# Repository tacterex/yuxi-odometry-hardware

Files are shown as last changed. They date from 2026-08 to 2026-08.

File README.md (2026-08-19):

# YUXI ODOMETRY HARDWARE DOCUMENTATION

## External References

* For **software documentation**, see the [YUXI Odometry Software repository](https://github.com/tacterex/yuxi-odometry-software-c).
* For the **FTC SDK library**, see: **TBA**

## Short description

This documentation provides instructions for assembling and using the YUXI ODOMETRY SET.

This document does not cover the electronic assembly of the odometry set. For mechanical assembly instructions, refer to the hardware documentation linked above. Instead, this document focuses on the electronic schematics, firmware, and software capabilities of the system.

Keep in mind that the electronics assembly affects some aspects of the mechanical assembly. Therefore, make sure to read both the hardware and software documentation carefully before starting the assembly.

## Recommended 3D Printer Settings

The 3D-printed parts were designed and tested using the following printer settings:

| Setting | Recommended value |
| --- | --- |
| Printer | Prusa i3 MK3S |
| Nozzle size | 0.2 mm |
| Material | PLA / PETG / ABS  |
| Layer height | 0.1mm |
| First layer height | 0.15mm |

> **Note:** The dimensional tolerances were calibrated specifically for the Prusa i3 MK3S. Depending on your printer and its calibration, you may need to adjust the tolerances to achieve the intended fit.

## Bill of Materials

### Hardware

The following hardware is required to fully assemble the project:

| Part | Quantity |
| --- | ---: |
| [M3 locknuts](https://fixpro.ua/kontrgajka-m-3-6-cb-1000shtupak-1) | ~10* |
| [M3 nuts](https://epicentrk.ua/ua/shop/gayka-shestigrannaya-m3-130-sht-expert-fix.html) | ~10* |
| [M3 square nuts](https://fixpro.ua/gajka-kvadratna-nyzka-m-3-din562-1000sht-upak-15) | ~35* |
| [5 × 50 mm springs](https://epicentrk.ua/ua/shop/pruzhina-rastyazhenie-5x50-mm-4-sht.html) | 4 |
| [6 × 10 × 3 mm pulleys](https://podshipnik.ua/ua/product/pidshipnik-mr106-zz-craft-00042041) | 6 |
| [M3 × 20 mm countersunk screws](https://fixpro.ua/din965-gvint-m3h20-potgl-cb-ph-1000shtupak-1) | ~8* |
| [M3 × 35 mm screws](https://fixpro.ua/din933-bolt-m3h35-a2-pr-2155-335) | ~6* |
| [M3 × 12 mm button-head screws](https://fixpro.ua/iso7380-2-gvynt-m3h12-npkr-gl-10-9-cb-inb-2177-312) | ~8* |
| AS5600 magnets (supplied with breakout boards, [see software guide](https://github.com/tacterex/yuxi-odometry-software-c#bill-of-materials)) | 2 |

> **Note:** Quantities may change as the project is still under active development. It is recommended to purchase a few spare parts, especially for components with approximate quantities.

### Tools and Supplies

The following tools are required to assemble the project:

* 1.5 mm hex key
* Pliers
* Screwdriver
* 5.5 mm wrench/nutdriver

## Printing Guide

The `stl/` folder contains all the necessary files to print **one odometry pod** and **one Pinpoint Computer**.

To assemble a complete set, you will need:

* **2 × odometry pods**
* **1 × Pinpoint Computer**

The models are ready to be sliced and printed. However, pay close attention to the required **G-code pauses**. Some parts require hardware components to be inserted during the print. The corresponding cavities for these components are visible when slicing the models.

> **Note:** Make sure to insert the required G-code pauses at the appropriate layers before starting the print. Otherwise, you may not be able to install the hardware components correctly.

The `step/` folder contains assembled 3D models of the components. These models can be used as a reference when assembling the odometry pod and Pinpoint Computer.

Lower detailed description of printing settings is provided. Assume that height and layer number is specified for 0.15mm first layer and 0.1mm other layers, which may be different from your printer

### Encoder V2 Lower Part

**Quantity:** 1

**Bed-facing surface:** The lowest face with four square holes.

| Layer height (mm) | Layer | Description |
| ---: | ----: | --- |
| 9.15 | 91 | Insert four M3 square nuts into the corresponding cavities. |

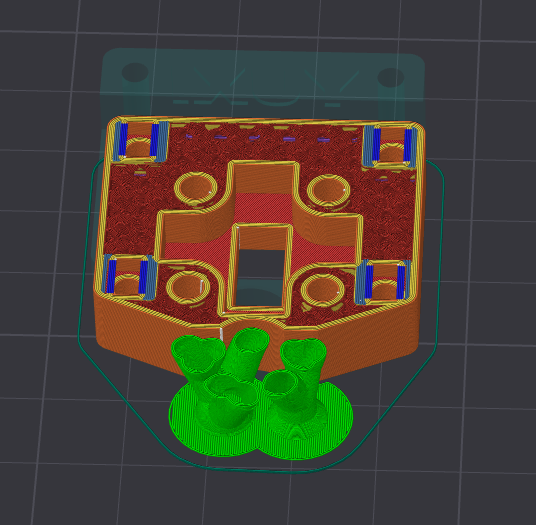
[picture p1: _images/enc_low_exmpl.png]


### Encoder V2 Upper Part

**Quantity:** 1

**Bed-facing surface:** Big flat face with 2 big round holes and 4 small round holes.

### Encoder V2 Body Spacer 1

**Quantity:** 1

**Bed-facing surface:** Flat surface

### Encoder V2 Body Spacer 1

**Quantity:** 2

**Bed-facing surface:** Flat surface

### Pod V2 Body

**Quantity:** 1

**Bed-facing surface:** The biggest flat surface

| Layer height (mm) | Layer | Description |
| ---: | ----: | --- |
| 7.95 | 79 | Insert six M3 square nuts into the corresponding cavities. |

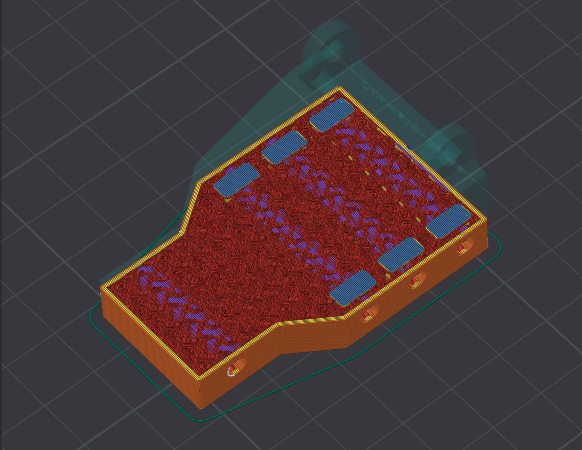
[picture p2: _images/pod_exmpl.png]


### Encoder V2 Driving Gear

**Quantity:** 1

**Bed-facing surface:** The biggest flat surface

| Layer height (mm) | Layer | Description |
| ---: | ----: | --- |
| 5.95 | 59 | Insert one M3 square nut into the corresponding cavity. |

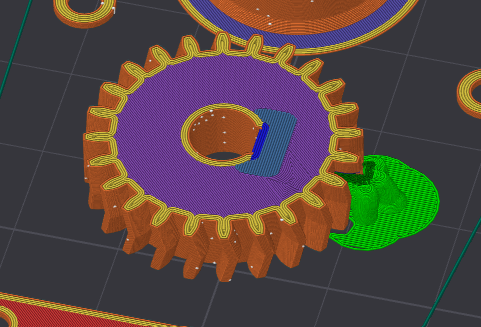
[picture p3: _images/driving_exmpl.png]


### Encoder V2 Driven Gear

**Quantity:** 1

**Bed-facing surface:** The biggest flat surface

| Layer height (mm) | Layer | Description |
| ---: | ----: | --- |
| 3.35 | 33 | Insert AS5600 magnet into the corresponding cavity. |
| 9.35 | 93 | Put 6x10mm pulley onto gear shaft |

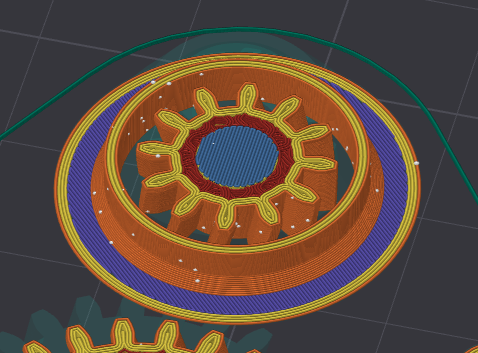
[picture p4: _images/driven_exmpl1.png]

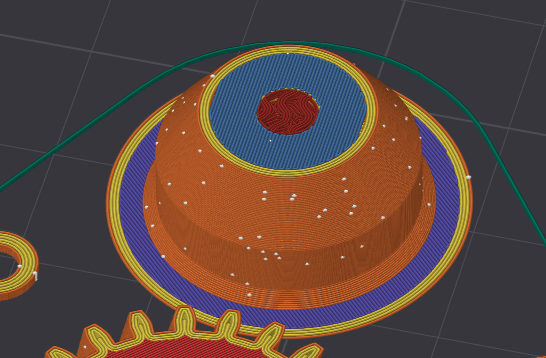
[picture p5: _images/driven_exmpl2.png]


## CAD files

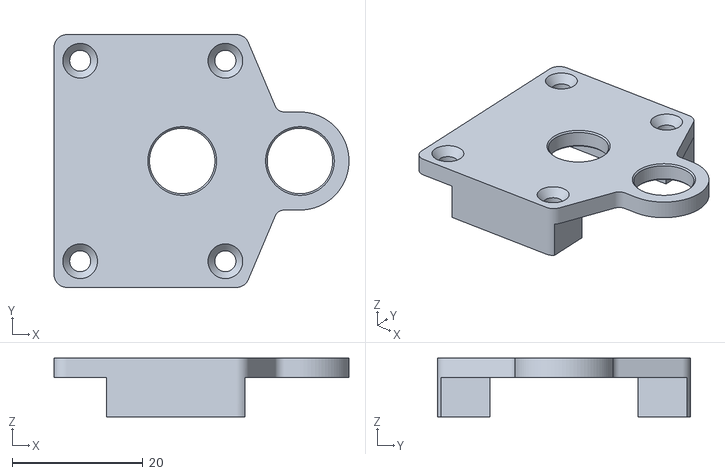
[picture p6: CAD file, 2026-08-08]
stl/pod v2/encoder v2 body upper part.stl
45.1 x 38.7 x 9.00

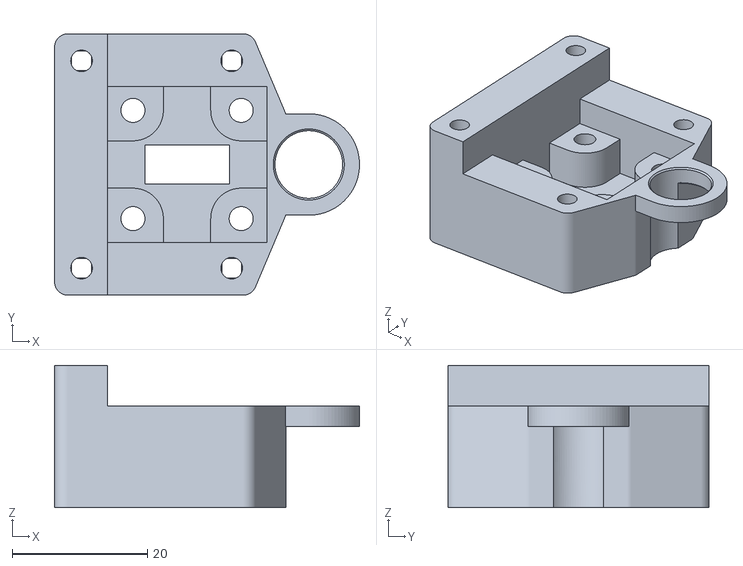
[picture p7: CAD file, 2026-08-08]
stl/pod v2/encoder v2 body lower part.stl
45.1 x 38.7 x 21.0

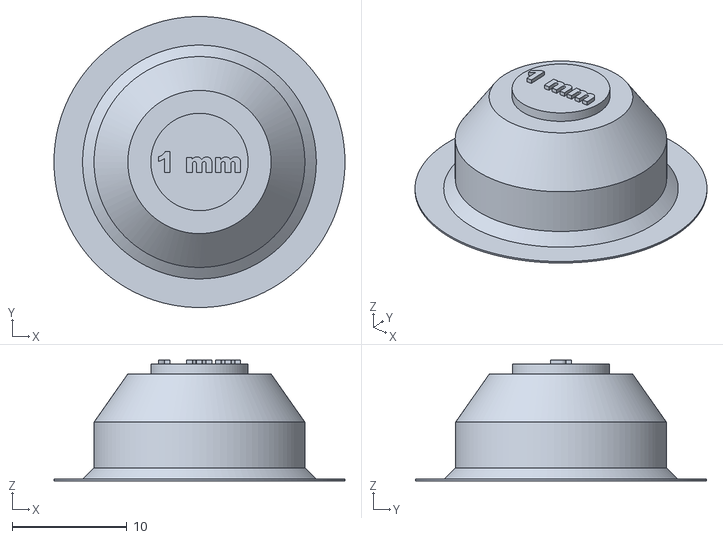
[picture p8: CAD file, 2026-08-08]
stl/pod v2/encoder v2 driven gear.stl
25.4 x 25.4 x 10.6

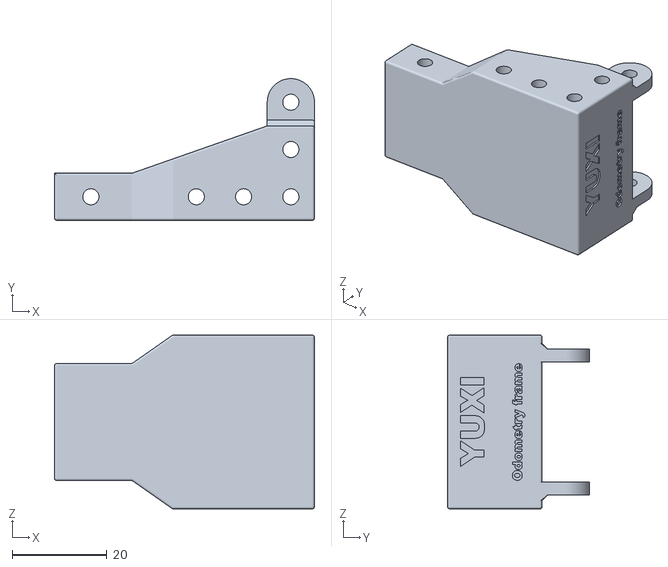
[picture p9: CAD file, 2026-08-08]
stl/pod v2/pod v2 body.stl
55.0 x 30.0 x 36.8

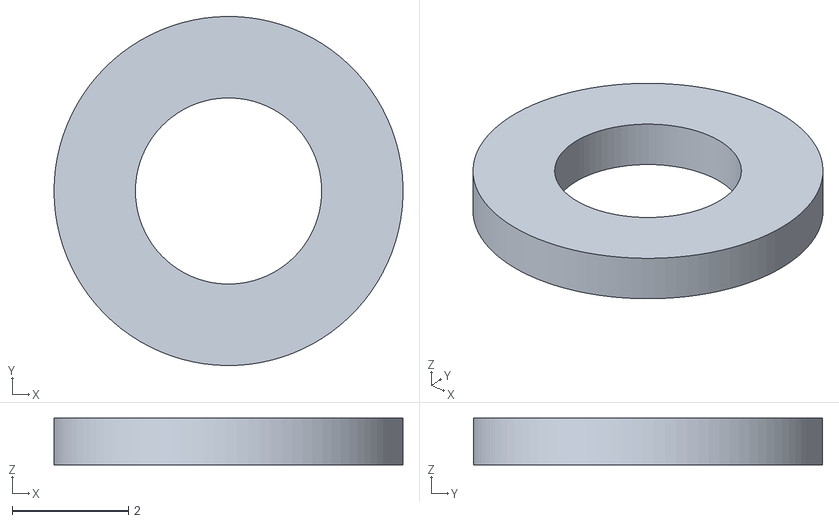
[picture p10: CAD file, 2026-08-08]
stl/pod v2/encoder v2 body spacer 2 (x2).stl
6.00 x 6.00 x 0.8

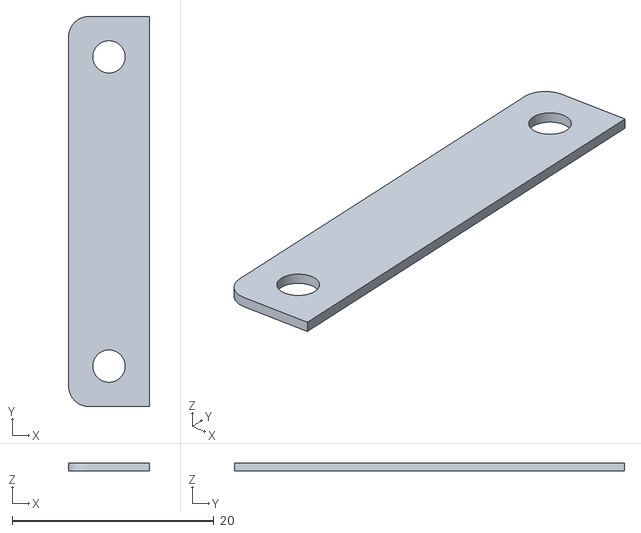
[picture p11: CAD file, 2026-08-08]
stl/pod v2/encoder v2 body spacer 1.stl
8.00 x 38.7 x 0.8
